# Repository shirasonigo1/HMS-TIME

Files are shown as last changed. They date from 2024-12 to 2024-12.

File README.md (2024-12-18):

Review Assignment Due Date (https://classroom.github.com/a/RUj6jsN1)
# *HMS Time* 
### Cyber-Physical Systems Project Documentation
HMS-Time

###

## 1. Concept

The pendulum clock has long captured the passage of time in hours, minutes, and seconds with its steady rhythmic swing. Inspired by the intricate mechanics of clockwork and fascinated by the nature of time perception, we set out to play with an idea of time that transcends the mechanical. Instead of being represented through the ticking of a traditional clock that persists in the background, what if we had the ability to shape and guide our own experience of time?

Our project, HMS Time, reimagines the abstract notion of time as not only something ticking down, but a medium to be felt and navigated through. Its sculptural shape takes the form of a ship, motored by a set of gears, and invites kinetic interaction through a webcam that detects body position. Audience members manipulate the motion of the ship and gears by forming their arms into the 12, 3, and 9 o'clock positions, thus becoming the clock with their own bodies. 

## 2. Setup and Initialization Guide

### Processing

1. **Install Libraries**:
   - Ensure the `oscP5` and `netP5` libraries are installed in Processing for OSC communication. You can install these from the Processing IDE's Library Manager.

2. **Set Up Serial and OSC**:
   - Connect your Arduino to your computer and check which serial port it’s assigned to. Uncomment and modify the line `port = new Serial(this, Serial.list()[index], 115200);` to select the correct port (replace `index` with the correct number, e.g., `Serial.list()[0]`).
   - OSC setup (`oscP5 = new OscP5(this, 12000);`) should already match Wekinator's output port if you’re using it.

3. **Run the Sketch**:
   - Run the Processing sketch to begin receiving OSC messages from Wekinator and sending serial commands to Arduino based on recognized gestures.

### Arduino

1. **Install Servo Library**:
   - Ensure the `Servo.h` library is available in the Arduino IDE. This library comes pre-installed with the Arduino IDE but can be added from the Library Manager if necessary.

2. **Connect the Hardware**:
   - Connect the servo motor signal wire to Arduino pin 8.
   - Connect the stepper motors as follows:
     - **Stepper Motor 1**: Connect its four control pins to Arduino pins 9, 10, 11, and 12.
     - **Stepper Motor 2**: Connect its four control pins to Arduino pins 4, 5, 6, and 7.
   - Ensure each motor’s power requirements match your setup (use external power if needed).

3. **Upload the Code**:
   - Upload the Arduino code to your board. Ensure the Serial Monitor is closed if it conflicts with Processing’s serial connection.

4. **Run the System**:
   - With the Arduino code uploaded and Processing running, test the system by sending gestures from Wekinator to verify that commands activate the motors as expected.

### Wekinator and VisionOSC

1. **Install Wekinator**:
   - Download and install Wekinator from [wekinator.org/downloads](http://wekinator.org/downloads).
   - Launch Wekinator and load the provided project files for this setup. Ensure the output ports are set to match Processing’s listening port (12000).

2. **Install VisionOSC**:
   - Download and install VisionOSC, a computer vision tool that sends OSC data compatible with Wekinator.

3. **Set Up VisionOSC**:
   - Open VisionOSC and configure it to detect hand gestures. Set the output port to Wekinator’s input port (default is 6448).

4. **Run VisionOSC and Wekinator**:
   - Run both VisionOSC and Wekinator. VisionOSC will capture gestures and send OSC data to Wekinator for classification.
   - In Wekinator, open the provided project training files, and run the model. Wekinator will then send the classified gesture data to Processing.

## Code Overview and Functional Mapping

### Wekinator Defined Classes

- **Class 1**: Hands pointing to 12 o'clock (both arms raised upward).
- **Class 2**: Hands pointing to 9 o'clock (left arm pointed to the side, right arm raised upward).
- **Class 3**: Hands pointing to 3 o'clock  (right arm pointed to the side, left arm raised upward).
- **Class 4**: Hands do nothing (neutral, resting state).
- **Class 5**: Human back facing the camera (no hand gestures visible).

### Processing Code Functional Overview

This code facilitates a gesture recognition system that receives input from Wekinator, processes sequences, and sends specific outputs to control an Arduino-connected motor system. The key functionalities are:

1. **Receiving Input from Wekinator**:
   - The code listens for OSC messages from Wekinator, which recognizes hand gestures.
   - Each gesture is converted into a numerical input that is added to a sequence, representing the user’s recent gestures.

2. **Gesture Sequence Recognition**:
   - Sequences of gestures are matched against predefined patterns to determine specific commands:
     - Example sequences: `[1]`, `[1, 2]`, `[1, 2, 3]`, and `[1, 3, 2]`.
     - Each pattern triggers a different action, like starting a motor, activating a specific part, or reversing.

3. **Output and Communication with Arduino**:
   - Based on the recognized gesture sequence, a corresponding command is generated and sent to the Arduino.
   - For example:
     - A single gesture `[1]` could start a motor.
     - Sequence `[1, 2, 3]` could activate a secondary motor or execute a multi-step process.
   - If a stop gesture (5) is recognized, the sequence is reset to await new input.

4. **Real-Time Visualization**:
   - A simple on-screen display shows the current sequence of gestures, helping users understand the recognized pattern and see which actions are triggered.

### Arduino Code Functional Overview

This Arduino code is designed to control a system with two stepper motors and one servo motor based on commands received through serial communication. The main functionalities are:

1. **Setting Up the Motors**:
   - The code defines pins for two stepper motors and one servo motor. Each motor has specific pins associated with it, which are used to control their movements.

2. **Receiving Commands**:
   - The Arduino listens for serial input to receive commands from an external source (e.g., a Processing program).
   - Different commands (1, 2, 3, 4, and 5) are mapped to activate or deactivate each motor:
     - **Command 1**: Activates the servo motor.
     - **Command 2**: Activates the first stepper motor.
     - **Command 3**: Activates the second stepper motor.
     - **Command 4**: Changes the direction of the stepper motors.
     - **Command 5**: Stops all motors.

3. **Controlling the Servo Motor**:
   - The servo motor is programmed to move smoothly back and forth between 0 and 180 degrees.
   - It uses a non-blocking approach, which allows it to run without interrupting the stepper motors’ operations.

4. **Controlling the Stepper Motors**:
   - The code continuously checks if either of the two stepper motors is active.
   - When activated, each stepper motor completes a sequence of steps, with each step corresponding to a specific pattern of signals sent to the motor’s pins.
   - The motor direction can be changed with the `Direction` variable, allowing the stepper to move forward or backward.

5. **Direction and Step Management**:
   - The `SetDirection` function updates the stepping sequence based on the direction variable, making sure the motors rotate in the correct direction.
   - When a sequence completes or reaches a limit, the code resets the step count to loop back through the motion.

## 3.  Mechanical Design

Our mechanical design for _HMS Time_ started with the idea of showcasing the intricate mechanisms of a clock, particularly the energy transfer and gear interactions that drive a traditional timepiece. Mechanical clocks rely on stored energy, generated by winding the mainspring, which fuels the clock’s movement. Similarly, in our project, we sought to highlight these fundamental principles of clockwork: energy storage, gear-driven motion, and the counting of controlled intervals.

In a traditional clock, a mainspring’s energy turns a series of gears, converting high torque and low rotation (from winding) into a precise, low-torque, high-rotation movement that drives the clock hands. The gears count each rotation in carefully timed intervals, regulating the clock’s progression. By combining large and small gears, the rotation rate is controlled precisely, just as the folio arm in a clock’s escapement allows for incremental release of energy. We echo this concept in _HMS Time_, where each user gesture engages different components: moving the boat forward (12 o’clock) mirrors the advancing of time, engaging the gears (3 o’clock) simulates energy transfer, and shifting the hands (9 o’clock) reflects the measured pace of time’s flow.

To capture the elegance of these mechanisms, we opted for a rack and pinion system to drive the boat’s linear movement. This choice allows us to demonstrate the visible transformation of energy into motion, offering an immediate, hands-on interaction with the “clock” of _HMS Time_. The rack and pinion mechanism enables clear, linear movement that aligns with the experience of watching gears in motion, while also supporting the project’s aesthetic and functional goals, creating a more accessible interpretation of time as something that can be guided and observed.

Rack and Pinion  

_Rack and pinion mechanism_

## 4. Hardware Design 

**Components:**
* 2 Step Motors; 1 to control the gears and 1 to control the rack and pinion
* 2 Drivers; to provide the necessary power to drive the motor
* 1 Servo – to control the clock hands
* 1 Capacitor - Elcectrical Storage
* 1 Resistor - Electrical Resistance
* Unlimited Wires! – Connecting components to the breadboard
* Webcam – Wekinator input
* 4 x (5mm x 11mm x 5mm) bearings & shaft (5mm); used for smoothness in mechanical design when connected to the motor.

Circuit Diagram  
_Circuit diagram_

## 5. Machine Learning 

**Model Evaluation**

To classify user poses, we used **VisionOSC’s PoseOSC** to capture keypoint data in ARR format. Each pose generated a data array of 52 values representing the x, y coordinates and confidence scores for 17 keypoints. This data was sent to Wekinator, where we used a K-Nearest Neighbors (KNN) model to classify five distinct poses:

1. **12 o’clock** - both arms up
2. **3 o’clock** - right arm extended
3. **9 o’clock** - left arm extended
4. **Neutral** - arms at rest
5. **Back to camera**

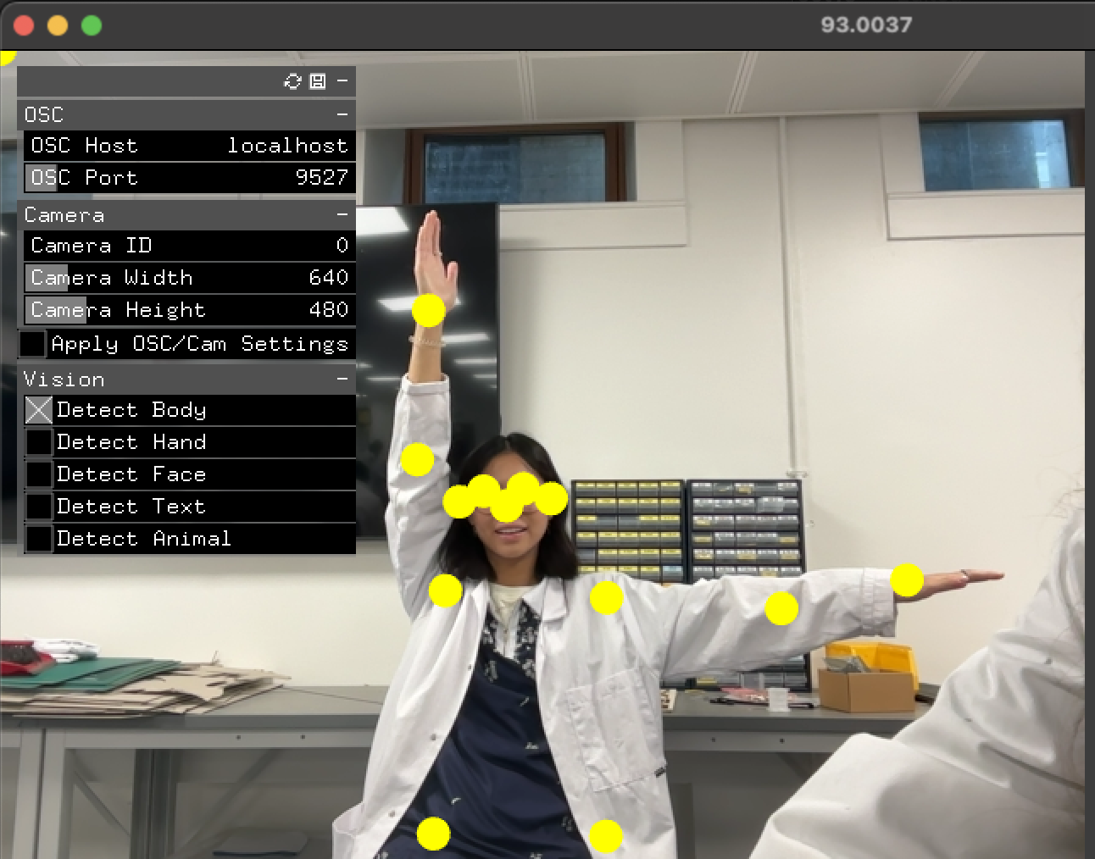
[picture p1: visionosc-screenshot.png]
VisionOSC
  

_Example pose: 9 o'clock_

We trained the model with data from approximately 20 participants, providing a diverse dataset to improve recognition accuracy across different body types and poses.

We selected KNN for its simplicity and effectiveness in handling small datasets with clear, distinct classes. KNN performs well with lower-dimensional data, making it suitable for pose classification where each pose has distinct features based on keypoint positions. Compared to more complex models, KNN was computationally efficient and easier to tune, allowing faster real-time classification with minimal latency. 

**Opportunities for Improvement**

We could enhance the model’s robustness by expanding the dataset to include varied lighting conditions and more diverse participants. Higher-resolution keypoint tracking or integrating advanced pose estimation techniques could further improve classification accuracy.

## 6. Credits
* Shira Sonigo - coding, mechanism development, product design
* Carrie Rong - concept development & machine learning
* Moin Mulla - woodworking

Cyber Physical Systems  
October-November 2024  
Advisor Dr. Rebecca Stewart, Charlotte Slingsby  
MSc Innovation Design Engineering Dyson School of Design Engineering, Imperial College London

This module was funded by Design Education Trust

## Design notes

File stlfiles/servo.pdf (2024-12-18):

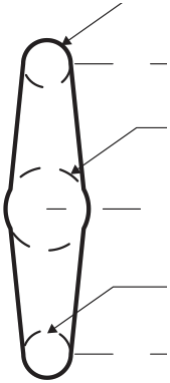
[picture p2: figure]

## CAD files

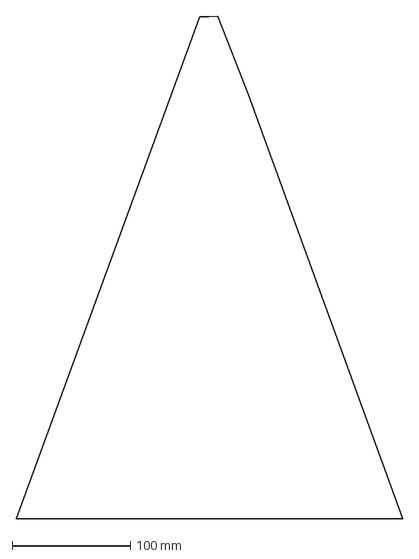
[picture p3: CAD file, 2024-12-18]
boat triangle acrylic.dxf
327.7 x 425.5 mm

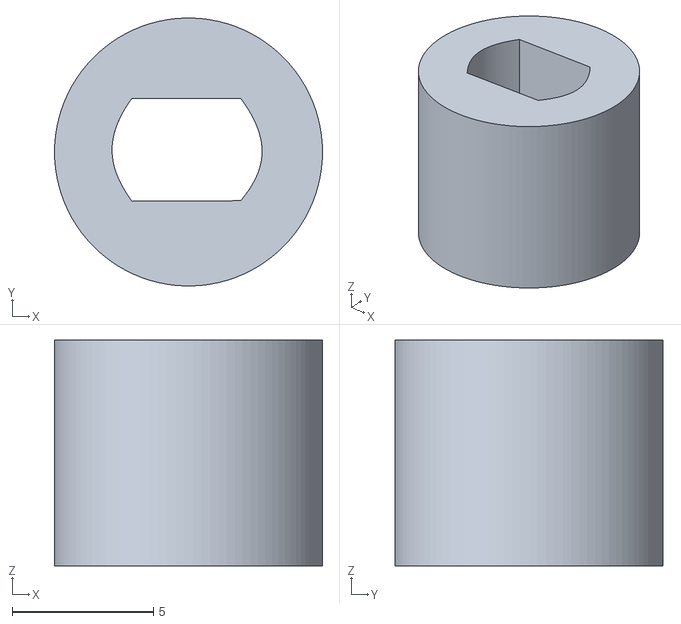
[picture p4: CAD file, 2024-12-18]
stlfiles/motor pin head v2.stl
9.50 x 9.49 x 8.00

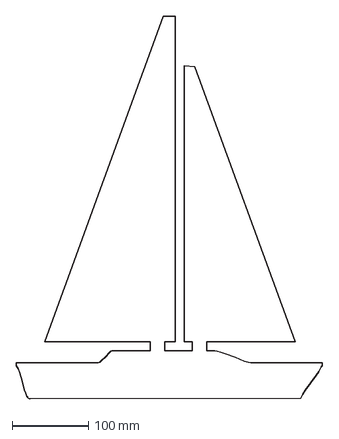
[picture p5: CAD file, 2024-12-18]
boat print.dxf
400.5 x 500.0 mm

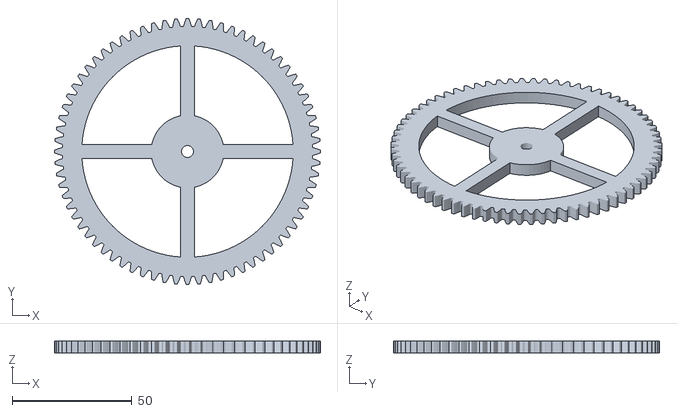
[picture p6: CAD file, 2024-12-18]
stlfiles/gear hour v2.stl
111.0 x 111.0 x 5.00

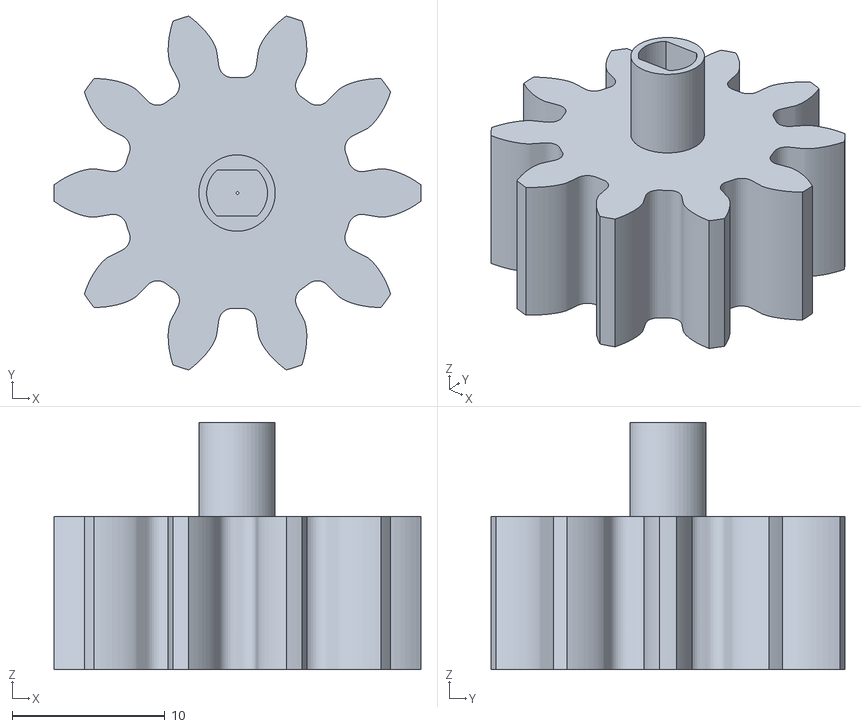
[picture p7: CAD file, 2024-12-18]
stlfiles/Clockgears 10.stl
24.0 x 23.1 x 16.2

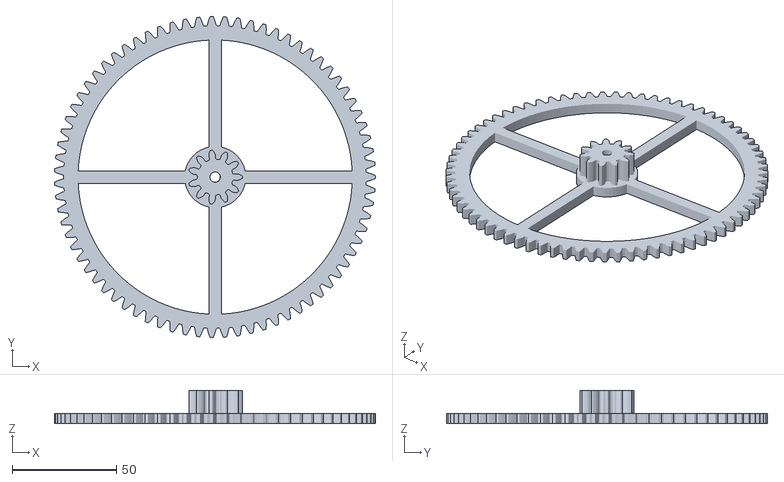
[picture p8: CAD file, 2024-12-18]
stlfiles/gear 75 v4.stl
154.0 x 154.0 x 16.0

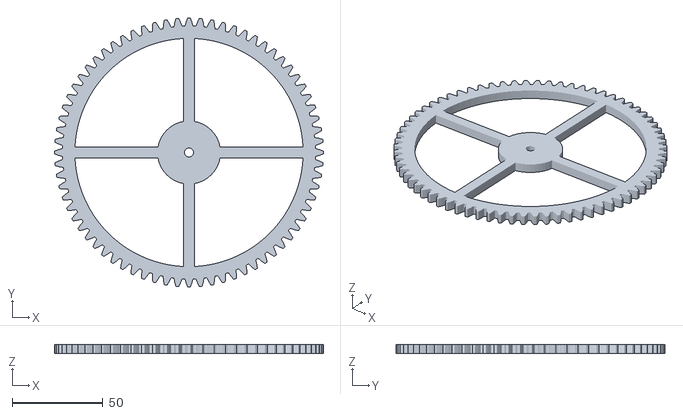
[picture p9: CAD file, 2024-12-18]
stlfiles/hour 2 v1.stl
148.0 x 148.0 x 5.00

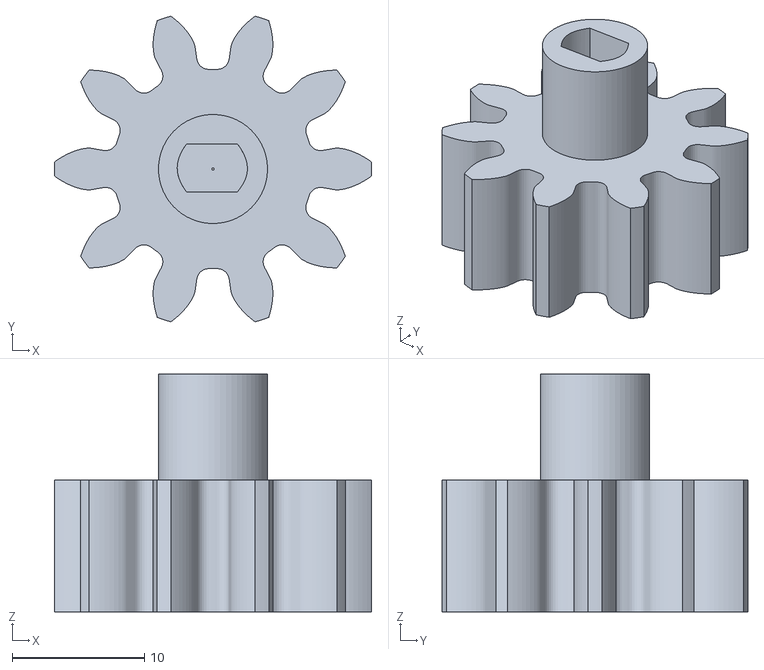
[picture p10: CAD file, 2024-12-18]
stlfiles/gear 10 v2.stl
24.0 x 23.1 x 18.0

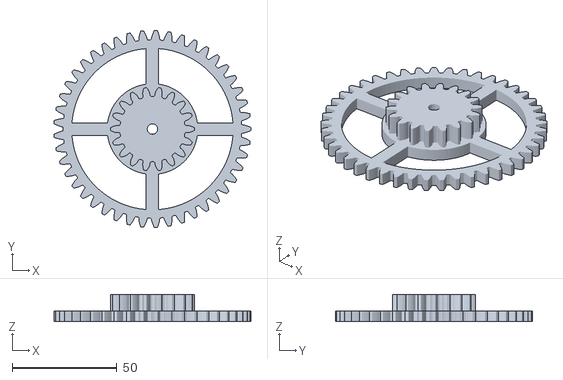
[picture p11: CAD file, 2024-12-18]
stlfiles/gear 45.18 v3.stl
93.9 x 94.0 x 13.0

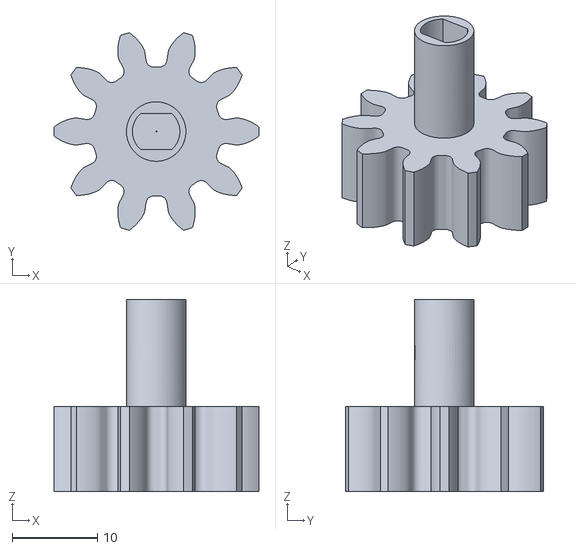
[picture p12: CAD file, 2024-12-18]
stlfiles/Clockgears v5.stl
24.0 x 23.1 x 22.5

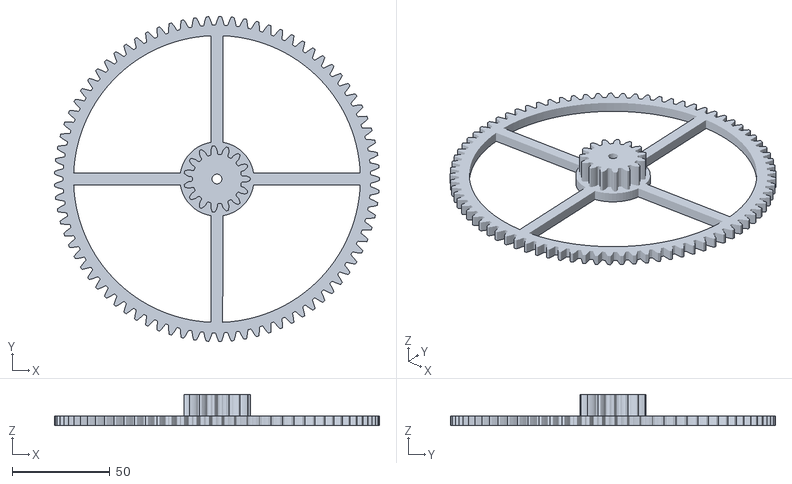
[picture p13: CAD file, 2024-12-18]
stlfiles/gear minutes v2.stl
166.0 x 166.0 x 16.0

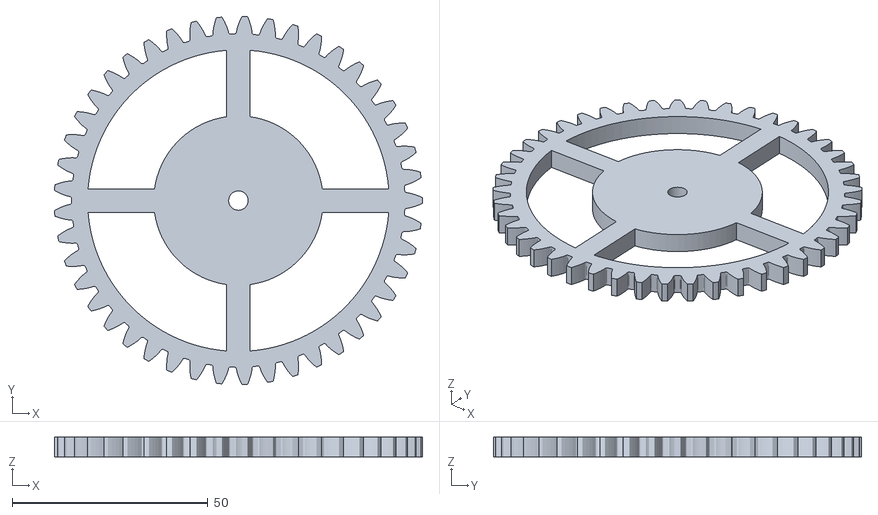
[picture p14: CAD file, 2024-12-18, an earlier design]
stlfiles/gear 45.18 v2.stl
93.9 x 94.0 x 5.00

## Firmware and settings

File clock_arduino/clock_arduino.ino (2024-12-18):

#include <Servo.h>

Servo myservo;
int servoPos = 0;           // Current position of the servo
int servoIncrement = 1;     // Step size (1 degree at a time)
unsigned long lastServoMove = 0; // Time of last servo movement
const int servoInterval = 15;    // Interval for servo movement in ms

// clock stepper
#define IN1 12
#define IN2 11
#define IN3 10
#define IN4 9

// hand stepper
#define IN5 7
#define IN6 6
#define IN7 5
#define IN8 4

int stepper1[4] = {IN1, IN2, IN3, IN4};
int stepper2[4] = {IN5, IN6, IN7, IN8};

int Steps = 0;
boolean Direction = false;
unsigned long last_time_stepper_1;
unsigned long last_time_stepper_2;
unsigned long currentMillis;
int steps_left_1 = 4095;
int steps_left_2 = 4095;
long time;
boolean servo_active = false;
boolean stepper1_active = false;
boolean stepper2_active = false;

void setup() {
  Serial.begin(115200);

  // Stepper motor pins
  pinMode(IN1, OUTPUT);
  pinMode(IN2, OUTPUT);
  pinMode(IN3, OUTPUT);
  pinMode(IN4, OUTPUT);
  pinMode(IN5, OUTPUT);
  pinMode(IN6, OUTPUT);
  pinMode(IN7, OUTPUT);
  pinMode(IN8, OUTPUT);
  
  // Servo motor setup
  myservo.attach(8);
  myservo.write(servoPos);
}

void loop() {
  
  // Wait for osc message
  if (Serial.available() > 0) {
    char input =  Serial.read();
    Serial.println(input);
    // run se servo
    if (input == '1') {
      Direction = false;
      servo_active = true;
    } else if (input == '2') {
      stepper1_active = true;
    } else if (input == '3'){
      stepper2_active = true;
    } else if (input == '4'){
      Direction = true;
      stepper1_active = true;
      stepper2_active = true;
    } else if(input == '5') {
      servo_active = false;
      stepper1_active = false;
      stepper2_active = false;
    }
  }

  if (stepper1_active){
      if (steps_left_1 > 0) {
        currentMillis = micros();
        if (currentMillis - last_time_stepper_1 >= 1000) {
          stepper(1, stepper1);
          time = time + micros() - last_time_stepper_1;
          last_time_stepper_1 = micros();
          steps_left_1--;
        }
      } else {
      // Serial.println(time);
      //  Serial.println("Wait...!");
        steps_left_1 = 4095;
      }
    }

  if (stepper2_active){
      if (steps_left_2 > 0) {
        currentMillis = micros();
        if (currentMillis - last_time_stepper_2 >= 1000) {
          stepper(1, stepper2);
          time = time + micros() - last_time_stepper_2;
          last_time_stepper_2 = micros();
          steps_left_2--;
        }
      } else {
      // Serial.println(time);
      //  Serial.println("Wait...!");
        steps_left_2 = 4095;
      }
    }

  if (servo_active) {
    // Non-blocking servo movement
    unsigned long currentMillis = millis();
    if (currentMillis - lastServoMove >= servoInterval) {
      lastServoMove = currentMillis;
      servoPos += servoIncrement;

      if (servoPos >= 180 || servoPos <= 0) {
        servoIncrement = -servoIncrement;  // Reverse direction
      }
      myservo.write(servoPos);  // Move the servo to the new position
    }
  }
}

void stepper(int xw, int (&stepper)[4]) {
  for (int i = 0; i < 4; i++) {
      Serial.println(stepper[i]);
  }
  for (int x = 0; x < xw; x++) {
    switch (Steps) {
      case 0:
        digitalWrite(stepper[0], LOW); 
        digitalWrite(stepper[1], LOW);
        digitalWrite(stepper[2], LOW);
        digitalWrite(stepper[3], HIGH);
        break; 
      case 1:
        digitalWrite(stepper[0], LOW); 
        digitalWrite(stepper[1], LOW);
        digitalWrite(stepper[2], HIGH);
        digitalWrite(stepper[3], HIGH);
        break; 
      case 2:
        digitalWrite(stepper[0], LOW); 
        digitalWrite(stepper[1], LOW);
        digitalWrite(stepper[2], HIGH);
        digitalWrite(stepper[3], LOW);
        break; 
      case 3:
        digitalWrite(stepper[0], LOW); 
        digitalWrite(stepper[1], HIGH);
        digitalWrite(stepper[2], HIGH);
        digitalWrite(stepper[3], LOW);
        break; 
      case 4:
        digitalWrite(stepper[0], LOW); 
        digitalWrite(stepper[1], HIGH);
        digitalWrite(stepper[2], LOW);
        digitalWrite(stepper[3], LOW);
        break; 
      case 5:
        digitalWrite(stepper[0], HIGH); 
        digitalWrite(stepper[1], HIGH);
        digitalWrite(stepper[2], LOW);
        digitalWrite(stepper[3], LOW);
        break; 
      case 6:
        digitalWrite(stepper[0], HIGH); 
        digitalWrite(stepper[1], LOW);
        digitalWrite(stepper[2], LOW);
        digitalWrite(stepper[3], LOW);
        break; 
      case 7:
        digitalWrite(stepper[0], HIGH); 
        digitalWrite(stepper[1], LOW);
        digitalWrite(stepper[2], LOW);
        digitalWrite(stepper[3], HIGH);
        break; 
      default:
        digitalWrite(stepper[0], LOW); 
        digitalWrite(stepper[1], LOW);
        digitalWrite(stepper[2], LOW);
        digitalWrite(stepper[3], LOW);
        break; 
    }
    SetDirection();
  }
}

void SetDirection() {
  if (Direction) { 
    Steps++;
  } else {
    Steps--; 
  }
  if (Steps > 7) { Steps = 0; }
  if (Steps < 0) { Steps = 7; }
}

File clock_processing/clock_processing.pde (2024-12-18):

import oscP5.*;
import netP5.*;
import processing.serial.*;

OscP5 oscP5;
Serial port;
float[] inputSequence = {}; // Array to hold the sequence of inputs received from Wekinator
int maxSequenceLength = 3; // Maximum length of sequence to check

void setup() {
  size(400, 200);
  oscP5 = new OscP5(this, 12000); 
  
  println("Available serial ports:");
  printArray(Serial.list());
  port = new Serial(this, Serial.list()[4], 115200);
  
  // Set text properties for visualization
  textSize(20);
  textAlign(CENTER, CENTER);
}

void draw() {
  background(255);
  
  // Draw the current inputSequence on the screen
  drawSequence();
}

void oscEvent(OscMessage msg) {
  // Check for OSC message from Wekinator
  if (msg.checkAddrPattern("/wek/outputs") && msg.typetag().length() > 0) {
    float input = msg.get(0).floatValue();// Assume the input is an integer
    println(input);
    
    
    // Add the new input to the sequence if it's different from the last element
    if (inputSequence.length == 0 || input != inputSequence[inputSequence.length - 1]) {
      inputSequence = append(inputSequence, input);
    }
    
     // Limit sequence length
    if (inputSequence.length > maxSequenceLength) {
      inputSequence = subset(inputSequence, 1); // Keep only the last maxSequenceLength elements
    }
    
    // Determine output based on sequence and send to Arduino
    int output = getOutputForSequence(inputSequence);
    if (output != -1) {
      port.write(str(output));
      println("Output sent to Arduino: " + output);
      
      // Reset sequence if a specific output was recognized
      if (output == 5){
        inputSequence = new float[0];
      }
    }else if(inputSequence.length == 1){
        inputSequence = new float[0];
     }
  }
}


int getOutputForSequence(float[] sequence) {
  // Check the input sequence against known patterns
  // start boat
  if (sequence.length == 1 && sequence[0] == 1) {
    return 1;
    // start first stepper
  } else if (sequence.length == 2 && sequence[0] == 1 && sequence[1] == 2) {
    return 2;
    //start second stepper
  } else if (sequence.length == 3 && sequence[0] == 1 && sequence[1] == 2 && sequence[2] == 3) {
    return 3;
    //go back in time
  } else if (sequence.length == 3 && sequence[0] == 1 && sequence[1] == 3 && sequence[2] == 2) {
    return 4;
    // stop
  } else if (sequence.length == 3 && sequence[2] == 5) {
    return 5;
  }
  return -1; // No matching sequence found
}

void drawSequence() {
  // Draw the array on the screen as rectangles
  int boxSize = 50; // Size of each box representing an element in inputSequence
  int startX = 50;  // Starting x position
  int startY = height / 2; // y position to center the sequence vertically
  
  for (int i = 0; i < inputSequence.length; i++) {
    // Draw a rectangle for each element in the sequence
    fill(200, 200, 255);
    rect(startX + i * boxSize, startY, boxSize, boxSize);
    
    // Display the value of the element inside the rectangle
    fill(0);
    text(inputSequence[i], startX + i * boxSize + boxSize / 2, startY + boxSize / 2);
  }
}
